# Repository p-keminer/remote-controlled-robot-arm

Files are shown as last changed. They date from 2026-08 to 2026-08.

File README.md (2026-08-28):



<div align="center">




</div>

---

# IMU Robotic Arm

Ein tragbarer Controller uebertraegt Armbewegungen auf einen modifizierten
Adeept-5-DOF-Roboterarm. Drei `BNO055`-IMUs erfassen Hand, Unterarm und Oberarm;
ein Potentiometer steuert den Greifer.

Der Prototyp besitzt zwei bewusst getrennte Datenpfade:

```text
Realer Steuerpfad
3x BNO055 + Potentiometer
  -> ESP32-S3 Controller
  -> ESP-NOW, Kanal 1
  -> ESP32-S3 Receiver
  -> I2C, Slave 0x42
  -> Arduino-kompatibles ATmega328P-Board
  -> 5 Servos

Debug- und Twin-Pfad
ESP32-S3 Controller
  -> zweiter ESP-NOW-Peer
  -> ESP32-S3 Bridge
  -> WiFi / MQTT / Raspberry Pi
  -> Dashboard, MCP und ROS 2
```

Der Debug-/Twin-Stack ist ein aktiver Bestandteil des Projekts. Er beobachtet
und visualisiert den Sensorstrom, liegt aber nicht im realen Servo-Steuerpfad.

## Demos

### ROS-2-Digital-Twin

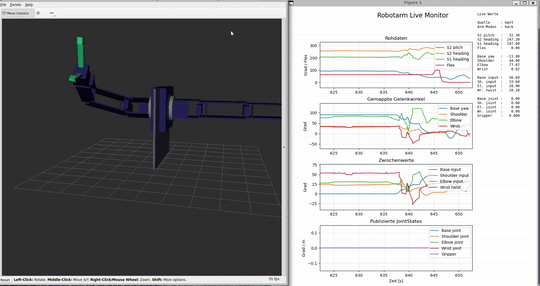
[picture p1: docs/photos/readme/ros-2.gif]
ROS-2-Digital-Twin


### Finaler Prototyp

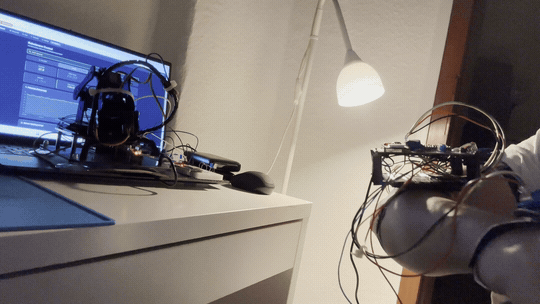
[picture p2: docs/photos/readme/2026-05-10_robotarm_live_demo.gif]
Finaler Prototyp Live-Demo


## Aktueller Stand

- Der vollstaendige Funk- und `I2C`-Pfad wurde am realen Prototyp getestet.
- Der eingecheckte Receiver startet weiterhin im `I2C`-Test-Sweep. Dieser Modus
  bewegt den Arm automatisch und ist keine Safety-Freigabe.
- `Live-I2C` und alle Live-Achsen bleiben im Repo-Default deaktiviert und werden
  nur bewusst per Compile-Flags aktiviert.
- Controller, Receiver-Default, Receiver-Live und Arduino-Sketch wurden mit den
  in [docs/BUILD.md](docs/BUILD.md#deutsch) festgehaltenen Versionen kompiliert.
- Bridge, `MQTT`, Dashboard, `MCP` und `ROS 2` bilden den aktiven Debug-/Twin-Pfad.
- Der Prototyp besitzt keine formale Produktiv-, Safety- oder Security-Freigabe.

Wichtig: Das Mapping des realen Arms und das Mapping der digitalen Zwillinge
sind derzeit nicht identisch. Die jeweiligen Implementierungen und Grenzen
sind in [docs/PROTOCOL.md](docs/PROTOCOL.md#deutsch) dokumentiert.

## Repository

- `firmware/`: aktive Controller-, Receiver-, Bridge- und Arduino-Firmware
- `firmware/archive/`: historische ESP-NOW-, UART- und Bring-up-Sketches
- `dashboard/`: Web-Dashboard und MQTT-MCP-Werkzeuge
- `ros2/`: ROS-2-Digital-Twin, Live-Monitor, Recorder und Replay
- `calibration/`: aktuelle Sensor-, Referenz- und Mappingdaten
- `docs/`: Hardware-, Protokoll-, Build- und Testdokumentation
- `tests/`: statische Guards fuer zeitkritische Firmwarepfade
- `scripts/`: lokale Pflege-, Sync- und Secret-Scan-Helfer
- `official_downloads/`: Herstellerlinks und Herkunftshinweise, kein Build-Input

## Einstieg

1. [docs/BUILD.md](docs/BUILD.md#deutsch) fuer Toolchain, Abhaengigkeiten und Builds
2. [docs/HARDWARE.md](docs/HARDWARE.md#deutsch) fuer Pins, Verdrahtung und Servolimits
3. [docs/PROTOCOL.md](docs/PROTOCOL.md#deutsch) fuer Steuer- und Debugdatenpfade
4. [calibration/README.md](calibration/README.md) fuer Referenzpose und Mapping
5. [SAFETY.md](SAFETY.md#deutsch) vor jeder Bewegung am realen Arm
6. [SECURITY.md](SECURITY.md#deutsch) vor Netz-, MQTT-, MCP- oder OTA-Betrieb
7. [docs/TESTING.md](docs/TESTING.md#deutsch) fuer bestaetigte und noch offene Nachweise
8. [dashboard/README.md](dashboard/README.md) und [ros2/README.md](ros2/README.md)
   fuer den Debug-/Twin-Stack

## Sicherheitsgrenze

Der Taster an `GPIO21` ist ein Software-Notaus-Request. Er trennt weder die
Servoversorgung noch das Drehmoment und ist kein fail-safe Hardware-Notaus.
Timeout- und Neutralverhalten fahren Zielwerte ueber die vorhandene
Slew-Begrenzung an. Details stehen in [SAFETY.md](SAFETY.md#deutsch).

## Lokale Konfiguration

Echte MAC-Adressen, WLAN-/MQTT-Zugangsdaten, Schluessel und lokale Pfade werden
nicht eingecheckt. Fuer Controller und Bridge existieren Templates; lokale
Dateien enden auf `*.local.*` und bleiben durch `.gitignore` ausgeschlossen.

Vor einem Push:

```bash
tr -d '\r' < scripts/secret_scan.sh | bash -s -- --tracked
```

## Lizenz

Projekt-eigene Inhalte stehen unter der [Apache License 2.0](LICENSE.md).
Verlinktes Hersteller- und Drittmaterial behaelt seine jeweiligen Lizenz- und
Urheberrechtsbedingungen.

<div align="center">



</div>

---

# IMU Robotic Arm

A wearable controller transfers arm movements to a modified Adeept 5-DOF
robotic arm. Three `BNO055` IMUs track the hand, forearm, and upper arm; a
potentiometer controls the gripper.

The prototype has two deliberately separated data paths:

```text
Real control path
3x BNO055 + potentiometer
  -> ESP32-S3 controller
  -> ESP-NOW, channel 1
  -> ESP32-S3 receiver
  -> I2C, slave 0x42
  -> Arduino-compatible ATmega328P board
  -> 5 servos

Debug and digital-twin path
ESP32-S3 controller
  -> second ESP-NOW peer
  -> ESP32-S3 bridge
  -> WiFi / MQTT / Raspberry Pi
  -> dashboard, MCP, and ROS 2
```

The debug/digital-twin stack is an active part of the project. It observes and
visualizes the sensor stream, but it is not part of the real servo-control path.

## Demos

### ROS 2 Digital Twin

ROS 2 digital twin

### Final Prototype

Final prototype live demo

## Current Status

- The complete radio and `I2C` path has been tested on the real prototype.
- The committed receiver still starts in the `I2C` test sweep. This mode moves
  the arm automatically and is not a safety approval.
- `Live I2C` and all live axes remain disabled in the repository defaults and
  are enabled deliberately through compile flags only.
- The controller, receiver default, receiver live configuration, and Arduino
  sketch were compiled with the versions recorded in [docs/BUILD.md](docs/BUILD.md#english).
- The bridge, `MQTT`, dashboard, `MCP`, and `ROS 2` form the active debug/digital-twin path.
- The prototype has no formal production, safety, or security approval.

Important: The real-arm mapping and the digital-twin mapping are currently not
identical. Their respective implementations and limitations are documented in
[docs/PROTOCOL.md](docs/PROTOCOL.md#english).

## Repository

- `firmware/`: active controller, receiver, bridge, and Arduino firmware
- `firmware/archive/`: historical ESP-NOW, UART, and bring-up sketches
- `dashboard/`: web dashboard and MQTT MCP tools
- `ros2/`: ROS 2 digital twin, live monitor, recorder, and replay
- `calibration/`: current sensor, reference, and mapping data
- `docs/`: hardware, protocol, build, and test documentation
- `tests/`: static guards for time-critical firmware paths
- `scripts/`: local maintenance, synchronization, and secret-scan helpers
- `official_downloads/`: manufacturer links and provenance notes, not a build input

## Getting Started

1. [docs/BUILD.md](docs/BUILD.md#english) for the toolchain, dependencies, and builds
2. [docs/HARDWARE.md](docs/HARDWARE.md#english) for pins, wiring, and servo limits
3. [docs/PROTOCOL.md](docs/PROTOCOL.md#english) for control and debug data paths
4. [calibration/README.md](calibration/README.md) for the reference pose and mapping
5. [SAFETY.md](SAFETY.md#english) before moving the real arm
6. [SECURITY.md](SECURITY.md#english) before operating networking, MQTT, MCP, or OTA
7. [docs/TESTING.md](docs/TESTING.md#english) for confirmed and outstanding evidence
8. [dashboard/README.md](dashboard/README.md) and [ros2/README.md](ros2/README.md)
   for the debug/digital-twin stack

## Safety Boundary

The button on `GPIO21` is a software emergency-stop request. It disconnects
neither servo power nor torque and is not a fail-safe hardware emergency stop.
Timeout and neutral behavior approach their targets through the existing slew
limit. See [SAFETY.md](SAFETY.md#english) for details.

## Local Configuration

Real MAC addresses, WiFi/MQTT credentials, keys, and local paths are not
committed. Templates are available for the controller and bridge; local files
end in `*.local.*` and remain excluded through `.gitignore`.

Before pushing:

```bash
tr -d '\r' < scripts/secret_scan.sh | bash -s -- --tracked
```

## License

Project-owned content is available under the [Apache License 2.0](LICENSE.md).
Linked manufacturer and third-party material retains its respective licensing
and copyright terms.

<div align="center">



</div>

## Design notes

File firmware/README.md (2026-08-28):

# Firmware

## Aktive Komponenten

| Pfad | Aufgabe |
|---|---|
| `esp32_controller/` | drei BNO055 ueber PCA9548A lesen, Potentiometer erfassen und `ImuPaket v4` senden |
| `esp32_receiver/` | ESP-NOW-Pakete validieren, auf Servo-Zielbytes abbilden und per I2C senden |
| `arduino_arm/` | I2C-Frames validieren, Servolimits und Slew-Rate anwenden |
| `esp32_bridge/` | zweiten ESP-NOW-Peer beobachten und Daten per MQTT an den Debug-/Twin-Stack geben |
| `archive/` | historische ESP-NOW-, UART- und Bring-up-Sketches; nicht aktiv bauen oder flashen |

## Steuerpfad

```text
esp32_controller/esp32_controller.ino
  -> ESP-NOW, ImuPaket v4, Kanal 1
esp32_receiver/esp32_receiver.ino
  -> I2C Frame V1, GPIO13/14, Slave 0x42
arduino_arm/arduino_arm.ino
  -> 5 Servos
```

Der Receiver-Default ist absichtlich konservativ:

```c
RECEIVER_MODE_TEST_SWEEP=1
RECEIVER_MODE_LIVE_I2C=0
RECEIVER_LIVE_ENABLE_BASIS=0
RECEIVER_LIVE_ENABLE_SHOULDER=0
RECEIVER_LIVE_ENABLE_ELBOW=0
RECEIVER_LIVE_ENABLE_WRIST=0
RECEIVER_LIVE_ENABLE_GRIPPER=0
```

Der Live-All-Axes-Build und der reale Prototyptest wurden bewusst ueber
Compile-Flags durchgefuehrt. Die exakten Befehle stehen in
[docs/BUILD.md](../docs/BUILD.md); Testgrenzen stehen in
[docs/TESTING.md](../docs/TESTING.md).

## Debug-/Twin-Pfad

Der Controller kann dasselbe Paket an einen zweiten ESP-NOW-Peer senden. Die
Bridge leitet diesen Beobachtungsstrom ueber WiFi/MQTT zum Raspberry Pi weiter.
Dashboard, MCP und ROS 2 sind aktive Debugwerkzeuge, aber keine Glieder des
Servo-Steuerpfads.

- Bridge-Firmware: `esp32_bridge/esp32_bridge.ino`
- Dashboard und MCP: [dashboard/README.md](../dashboard/README.md)
- ROS-2-Digital-Twin: [ros2/README.md](../ros2/README.md)

## Lokale Konfiguration

Vor einem lokalen Build die Templates kopieren und nur die gitignorierten
lokalen Dateien befuellen:

- Controller: `esp32_controller/peer_config.template.h` -> `peer_config.local.h`
- Bridge: `esp32_bridge/peer_config.template.h` -> `peer_config.local.h`
- Bridge: `esp32_bridge/wifi_config.template.h` -> `wifi_config.local.h`

Keine echten MACs, WLAN-/MQTT-Zugangsdaten oder Schluessel committen.

## Kanonische Dokumentation

- Build und Versionen: [docs/BUILD.md](../docs/BUILD.md)
- Verdrahtung und Servolimits: [docs/HARDWARE.md](../docs/HARDWARE.md)
- Pakete, Topics und Mappings: [docs/PROTOCOL.md](../docs/PROTOCOL.md)
- Referenzpose und Kalibrierung: [calibration/README.md](../calibration/README.md)
- Safety-Grenzen: [SAFETY.md](../SAFETY.md)
- Security-Grenzen: [SECURITY.md](../SECURITY.md)
- Teststatus: [docs/TESTING.md](../docs/TESTING.md)

Die Pfade `I2C_FRAME_V1.md` und `SERVO_UART_DESIGNENTSCHEIDUNGEN.md` bleiben
als kurze Kompatibilitaetsdokumente erhalten, weil aktive und archivierte
Quellkommentare darauf verweisen.

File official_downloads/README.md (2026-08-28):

# Herstellerreferenz

Dieser Ordner enthaelt nur Bezugsquellen und Herkunftshinweise zum verwendeten
Adeept-Grundkit. Herstellerarchive und entpackte Herstellerdateien werden nicht
versioniert; sie sind kein Build-Input und beschreiben nicht den heutigen
Prototyp mit ESP32-Steuerpfad, Potentiometer-Greifer und Debug-/Twin-Stack.

Offizielle Bezugsquellen:

- [Adeept Robotic Arm UNO](https://www.adeept.com/robotic-arm-uno_p0118.html)
- [Adeept Learn, Detail 64](https://www.adeept.com/learn/detail-64.html)

Regeln:

- Herstellerarchive und entpackte Vendor-Baeume werden nicht eingecheckt.
- Bei Bedarf werden Herstellerdateien erneut aus den offiziellen Quellen bezogen.
- Aktive Entscheidungen stehen in [`docs/HARDWARE.md`](../docs/HARDWARE.md),
  nicht in den Herstellerbeispielen.

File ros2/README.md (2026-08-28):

# ROS 2 Digital Twin

Dieses Verzeichnis enthaelt den ROS-2-/RViz-Digital-Twin fuer den Adeept
5-DOF-Arm. Er liest Telemetrie aus dem MQTT-Debugpfad, berechnet
Gelenkpositionen und visualisiert oder protokolliert sie. Er steuert keine
Servos und ist kein Safety-Pfad.

```text
Bridge --MQTT robotarm/imu--> mqtt_bridge
       --ROS /joint_states--> robot_state_publisher --> RViz
                            \-> Recorder / Live-Monitor / Replay
```

## Inhalt

| Pfad | Aufgabe |
| --- | --- |
| `src/robotarm_description/urdf/` | Tisch- und Wandmodell |
| `src/robotarm_description/meshes/` | eingecheckte STL-Geometrien |
| `src/robotarm_description/launch/` | RViz-, Live-, Debug- und Replay-Launches |
| `src/robotarm_description/robotarm_description/mapping.py` | Twin-Mapping |
| `.../mqtt_bridge.py` | MQTT-Eingang und ROS-Publisher |
| `.../debug_recorder.py` | JSONL-Aufzeichnung einer Debug-Session |
| `.../imu_replayer.py` | zeitgetreues Replay von `raw_imu.jsonl` |
| `.../live_monitor.py` | Matplotlib-Livekurven |
| `.../debug_plot.py` | PNG-Kurven aus einer Session |
| `start_*.sh`, `plot_*.sh`, `stop_*.sh` | Start- und Diagnosehelfer |

## Voraussetzungen und Build

Der verifizierte Zielkontext ist ROS 2 Jazzy unter WSL mit WSLg. Benoetigt
werden mindestens:

- ROS-Pakete fuer `rclpy`, `sensor_msgs`, `std_msgs`, `std_srvs`,
  `robot_state_publisher`, `joint_state_publisher_gui` und `rviz2`
- Python-Pakete `paho-mqtt` und `matplotlib`
- ein Tk-Backend fuer den Live-Monitor
- `numpy` und `trimesh` nur, wenn die eingecheckten STL-Dateien neu erzeugt
  werden sollen

Build ab dem Verzeichnis `ros2/`:

```bash
cd <pfad-zum-repo>/ros2
source /opt/ros/jazzy/setup.bash
rosdep install --from-paths src --ignore-src -r -y
colcon build --symlink-install --packages-select robotarm_description
source install/setup.bash
```

Vor einem Live-Start muessen sich `paho.mqtt.client` und fuer den Debug-Start
auch `matplotlib` im selben Python-Kontext wie ROS importieren lassen.

## MQTT konfigurieren

Die Startskripte laden optional eine lokale, gitignorierte Datei:

```bash
cp robotarm_mqtt.template.sh robotarm_mqtt.local.sh
chmod 600 robotarm_mqtt.local.sh
```

| Variable | Standard ohne lokale Datei | Bedeutung |
| --- | --- | --- |
| `ROBOTARM_MQTT_HOST` | `localhost` | Mosquitto-Host |
| `ROBOTARM_MQTT_PORT` | `1883` | MQTT-Port |
| `ROBOTARM_MQTT_USER` | `mcp_reader` | nur lesender Broker-Account |
| `ROBOTARM_MQTT_PASS` | leer | lokales Passwort |
| `ROBOTARM_TARGET_ARM` | `both` | `front`, `back` oder `both` |
| `ROBOTARM_RECORD_DEBUG` | `true` | Recorder im Debug-Launch |
| `ROBOTARM_SHOW_LIVE_MONITOR` | `true` | Live-Monitor im Debug-Launch |
| `ROBOTARM_DEBUG_DIR` | `ros2/debug_sessions` | lokale Session-Ausgabe |

Passwoerter und lokale Hosts werden nur in `robotarm_mqtt.local.sh` gepflegt.
Die Datei darf nicht eingecheckt werden.

## Starten

Alle folgenden Befehle gelten **nach** `cd <pfad-zum-repo>/ros2`; deshalb
enthalten die Pfade kein zusaetzliches `./ros2/`.

Nur RViz mit Gelenkslidern, ohne MQTT:

```bash
./start_rviz.sh          # Tischmodell
./start_rviz_wall.sh     # zwei gespiegelte Wandarme
```

Live-Twin aus `robotarm/imu`:

```bash
./start_live_wall.sh
```

Live-Twin mit Recorder und optionalem Matplotlib-Monitor:

```bash
./start_live_wall_debug.sh
```

Die beiden Live-Skripte rufen vorher `stop_live_wall_stack.sh` auf. Dieses
Skript beendet passende ROS-/RViz-/Monitor-Prozesse mit `kill -9` und sollte
daher nur in der dafuer vorgesehenen WSL-Sitzung verwendet werden.

Der Wand-Launch kennt drei Zielmodi:

- `front`: nur linker Arm
- `back`: nur rechter Arm
- `both`: beide gespiegelten Arme

Zur Laufzeit wechselt der Dienst zyklisch `front -> back -> both`:

```bash
ros2 service call /toggle_arm std_srvs/srv/Trigger '{}'
```

## Debug-Session, Replay und Plot

Der Debug-Launch schreibt standardmaessig nach
`debug_sessions/<YYYYMMDD_HHMMSS>/`:

- `raw_imu.jsonl`
- `mapping.jsonl`
- `joint_states.jsonl`
- `session.json`
- optional `curves.png`

`debug_sessions/` ist gitignoriert. Vor einem Replay sollte ein laufender
Live-Stack explizit beendet werden:

```bash
./stop_live_wall_stack.sh
./start_replay_wall.sh debug_sessions/<timestamp>/raw_imu.jsonl
./start_replay_wall.sh debug_sessions/<timestamp>/raw_imu.jsonl 0.5
```

Plot der neuesten oder einer bestimmten Session:

```bash
./plot_debug_session.sh
./plot_debug_session.sh debug_sessions/<timestamp>
```

## Schnittstellen

### MQTT-Eingang

Der ROS-Node `mqtt_bridge` abonniert nur `robotarm/imu`. Die MQTT-Topics
`robotarm/status`, `robotarm/kalib` und `robotarm/ota/log` werden von diesem
Paket nicht konsumiert.

### ROS-2-Ausgabe

| ROS-Name | Typ | Erzeuger | Aktiv wenn |
| --- | --- | --- | --- |
| `/joint_states` | `sensor_msgs/JointState` | MQTT-Bridge oder Replay | Live/Replay |
| `/robotarm/debug/raw_imu` | `std_msgs/String` | MQTT-Bridge oder Replay | `publish_debug=true` |
| `/robotarm/debug/mapping` | `std_msgs/String` | MQTT-Bridge oder Replay | `publish_debug=true` |
| `robot_description` | Node-Parameter | Launch-Datei | jeder Launch |
| `/tf`, `/tf_static` | TF | `robot_state_publisher` | jeder Launch |
| `/toggle_arm` | `std_srvs/Trigger` | MQTT-Bridge | Live |

Die Namen mit fuehrendem `/` sind ROS-2-Namen und duerfen nicht als
MQTT-Topics dokumentiert oder in Mosquitto abonniert werden.

## Twin-Mapping

`mapping.py` und `dashboard/web/js/robotarm_3d.js` verwenden denselben
Twin-Stand:

| Gelenk | Twin-Eingang |
| --- | --- |
| Basis | `88.9 - S2.pitch`, visuell `+90..-90` Grad |
| Schulter | negierte Heading-Abweichung von `S2` zu `280.8` Grad |
| Ellbogen | relative Heading-Abweichung `S1` zu `S2` |
| Wrist | negierte relative Roll-Abweichung `S0` zu `S1`, Offset und Stabilisierung |
| Greifer | `f` in Prozent, invertiert auf die visuelle Oeffnung und geglaettet |

Dieses Twin-Mapping ist nicht identisch mit dem Realarm-Mapping in
[`live_i2c_mapping.h`](../firmware/esp32_receiver/live_i2c_mapping.h). Dort
weichen unter anderem Basisrichtung, Schulterreferenz/-fenster und die
Wrist-Fallback-/Nullungslogik ab. Konstanten duerfen deshalb nicht ungeprueft
zwischen Twin und Receiver kopiert werden.

## Test und Diagnose

Pakettests nach einem Build:

```bash
colcon test --packages-select robotarm_description
colcon test-result --verbose
```

Schneller Laufzeitcheck bei gestartetem Live-Stack:

```bash
ros2 topic echo --once /joint_states
ros2 topic hz /joint_states
ros2 topic echo --once /robotarm/debug/mapping
```

Der letzte Befehl liefert nur im Debug-Launch Daten. Bei DDS-Problemen kann
`test_dds.template.sh` nach `test_dds.local.sh` kopiert und der lokale Pfad
angepasst werden.

## Bekannte Grenzen

- Das Paket ist ein Debug-/Simulationspfad und besitzt keinen Servo-Ausgang.
- `fastdds_profile.xml` erzwingt Shared Memory und ist fuer Prozesse auf
  demselben WSL-Host gedacht, nicht fuer verteilte ROS-Rechner.
- Der Live-Pfad stabilisiert Wrist und Greifer zustandsbehaftet. Das Replay
  nutzt zwar dasselbe Grundmapping, wendet diese Live-Stabilisierung aber
  derzeit nicht an und ist daher nicht samplegenau identisch.
- `mapping.py` publiziert den Wrist-Zwischenwert als `roll_rel_deg`; Plot und
  Live-Monitor suchen aktuell noch `twist_rel_deg`. Die betreffende
  Zwischenwert-Kurve bleibt dadurch leer, waehrend Gelenkwinkel und
  `/joint_states` weiter funktionieren.
- Die Standard-Lintertests decken Stil ab, aber keine numerischen
  Mapping-Grenzfaelle.

Weitere Details stehen in
[`dashboard/README.md`](../dashboard/README.md),
[`docs/PROTOCOL.md`](../docs/PROTOCOL.md),
[`docs/TESTING.md`](../docs/TESTING.md) und
[`SECURITY.md`](../SECURITY.md).

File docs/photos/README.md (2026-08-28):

# docs/photos

## Zweck

Dieser Ordner enthaelt Bildnachweise fuer Aufbau, Montage, Sensorlage und Verkabelung.

## Aktueller Stand

Fotos des Stock-Aufbaus, des fruehen Bench-Setups und des finalen Prototypstands sind als JPG dokumentiert.
README- und Demo-GIFs werden getrennt unter `readme/` gepflegt.

## Inhalt

- `2026-03-24_roboterarm_seitenansicht.jpg` - Adeept-Arm Seitenansicht (Stock-Zustand)
- `2026-03-24_roboterarm_rueckansicht.jpg` - Adeept-Arm Rueckansicht (Stock-Zustand)
- `2026-03-24_roboterarm_basis_detail.jpg` - Adeept-Arm Basis-Detail (Stock-Zustand)
- `2026-03-26_bench_breadboards_uebersicht.jpg` - Bench-Setup mit Controller und Receiver Breadboards
- `2026-03-26_bench_breadboards_detail.jpg` - Bench-Breadboard Detail (IMU-Verkabelung)
- `2026-03-28_bench_aufbau_aktuell.jpg` - aktueller Bench-Aufbau
- `2026-05-10_robotarm_finaler_prototyp.jpg` - finaler Robotarm-Prototypstand
- `readme/` - GIFs und Medien fuer README-/Demo-Nachweise

## Regeln

- Fotos als JPG ablegen, damit sie ohne HEIC-Sonderunterstuetzung nutzbar bleiben
- Bilder so benennen, dass Datum, Zweck oder Aufbauzustand erkennbar sind
- wenn ein Foto eine Kalibrier- oder Sicherheitsentscheidung stuetzt, sollte es querreferenziert werden

## Schnittstellen/Abhaengigkeiten

- ergaenzt `hardware/`, `calibration/reference_poses/` und `docs/measurement_logs/`

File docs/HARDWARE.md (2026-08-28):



<div align="center">




</div>

---

# Hardware

Diese Datei ist die kompakte Hardware-Referenz des aktuellen Prototyps. Sie
beschreibt den real aufgebauten Projektpfad; Herstellerstand und fruehe
Breadboard-/UART-/Flex-Sensor-Staende sind keine aktive Verdrahtung.

Der Arm ist ein funktionsfaehiger Entwicklungsprototyp, aber kein
sicherheitszertifiziertes Produkt. Vor realer Bewegung gelten zusaetzlich die
Einschraenkungen aus [`SAFETY.md`](../SAFETY.md#deutsch).

## Aktive Komponenten

- Adeept 5-DOF Roboterarm mit ATmega328P-basiertem Driver Board
  (`arduino:avr:uno`)
- fuenf aktive AD002-Servos; der urspruengliche Schulterservo wurde durch den
  damaligen Reserveservo ersetzt, ein weiterer Reserveservo ist nicht vorhanden
- drei ESP32-S3-WROOM-1-N16R8: Controller, Receiver und separate Debug-Bridge;
  ein viertes Board ist Reserve
- Boardrevision v1.0 mit 16 MB Flash, 8 MB Octal-PSRAM und RGB-LED auf `GPIO48`
- drei GY-BNO055-Module an einem PCA9548A-Multiplexer
- 10-kOhm-Potentiometer als aktive Greifer-Eingabe
- zwei Molicel INR-18650-M35A im Adeept-Batteriehalter; zwei weitere Zellen als
  Wechselakkus, Ladegeraet XTAR VC4SL

Fuer die ESP32 gilt die Custom-FQBN
`esp32:esp32:robotic_arm_s3n16r8`. `GPIO35`, `GPIO36` und `GPIO37` sind durch das
Octal-PSRAM belegt und nicht fuer Projekt-I/O verfuegbar.

## Controller und Sensorik

| Signal | Anschluss | Gegenstelle / Funktion |
| --- | --- | --- |
| ADC Greifer | `GPIO1` | Poti-Wischer; 10-kOhm-Pull-down bleibt am Controller |
| I2C SDA | `GPIO8` | PCA9548A SDA |
| I2C SCL | `GPIO9` | PCA9548A SCL |
| IMU-Status S2 | `GPIO4` | blaue LED, Oberarm |
| IMU-Status S1 | `GPIO5` | rote LED, Unterarm |
| IMU-Status S0 | `GPIO6` | weisse LED, Hand/Wrist |
| Kommunikation | `GPIO7` | gruene LED |
| Fehler | `GPIO10` | externe FAULT-LED |
| Software-Stop | `GPIO21` | Taster nach GND, interner Pull-up |
| RGB | `GPIO48` | onboard, Fehler-/Stop-Anzeige |

PCA9548A-Adresse: `0x70`. Alle drei BNO055 verwenden hinter getrennten
Mux-Kanaelen die Adresse `0x29`.

| Mux-Kanal | Datenindex | Koerpersegment |
| --- | --- | --- |
| `0` | `S0` | Hand/Wrist |
| `1` | `S1` | Unterarm |
| `2` | `S2` | Oberarm |

Das Potentiometer ist im bestaetigten 2-Draht-Aufbau angeschlossen: `3.3 V` an
einem aeusseren Pin, Wischer an `GPIO1`; der vorhandene 10-kOhm-Pull-down zieht
den ADC-Knoten nach GND. Die aktiven Kalibrieranker stehen in
[`calibration/README.md`](../calibration/README.md).

## Receiver, Arduino und I2C

| Signal | ESP32-Receiver | Adeept-/Arduino-Board |
| --- | --- | --- |
| SDA | `GPIO13` | `A4`, OLED-Header Pin 3 |
| SCL | `GPIO14` | `A5`, OLED-Header Pin 4 |
| Masse | `GND` | `GND`, gemeinsamer Bezug |

- ESP32: I2C-Master mit `100 kHz`
- Arduino: I2C-Slave `0x42`
- Transport: festes 11-Byte-Frame V1
- das OLED muss waehrend dieser Verbindung ausgesteckt bleiben, weil es denselben
  Busanschluss belegt
- Receiver-Status: `GPIO4` I2C, `GPIO5` ESP-NOW/LINK, `GPIO48` RGB

Die aktive Definition liegt in
[`i2c_frame.h`](../firmware/esp32_receiver/i2c_frame.h) und
[`arduino_arm.ino`](../firmware/arduino_arm/arduino_arm.ino).

### I2C-Pegel: vor Betrieb verifizieren

Der ESP32-S3 arbeitet mit `3.3 V`, das ATmega328P-Board mit `5 V`. I2C ist
Open-Drain; der HIGH-Pegel wird daher durch die tatsaechlich vorhandenen
Pull-ups bestimmt. Eine funktionierende Bench-Verbindung beweist nicht, dass
am ESP32 ein zulaessiger Pegel anliegt. Die fruehere Annahme, interne
ATmega-Pull-ups seien ohne Pegelanpassung unkritisch, ist keine belastbare
Freigabe.

Vor erneutem Anschluss an einen ESP32:

1. alle Pull-ups auf Driver Board, OLED-Header und Zusatzmodulen identifizieren;
2. SDA und SCL im Leerlauf gegen GND messen;
3. sicherstellen, dass beide Leitungen auf der ESP32-Seite auf `3.3 V`
   hochgezogen werden und dort niemals oberhalb des Datenblattbereichs liegen;
4. bei `5 V` oder unbekannter Beschaltung einen bidirektionalen, fuer
   Standard-Mode-I2C geeigneten Levelshifter einsetzen oder die Pull-ups
   nachweislich auf `3.3 V` legen;
5. erst danach ESP32, Arduino und gemeinsame Masse verbinden.

`5 V` direkt an einem ESP32-S3-GPIO ist nicht freigegeben. Bis Pull-up-Spannung
und Leerlaufpegel dokumentiert sind, bleibt diese elektrische Schnittstelle ein
offener Safety-Punkt.

## Servoanschluesse und aktive Grenzen

Die reale Belegung weicht vom Adeept-Stock-Mapping ab. Die aktive Firmware
mappt jeweils den Bytebereich `0..255` auf die gemessenen Min-/Max-Werte.

| Gelenk | PWM-Pin | Stock-Poti | Min | Max | aktiver Start-/Rueckfallwert |
| --- | ---: | ---: | ---: | ---: | ---: |
| Basis | `D9` | `A0` | 12 Grad | 139 Grad | 75 Grad |
| Schulter | `D11` | `A6` | 35 Grad | 142 Grad | 88 Grad |
| Ellbogen | `D3` | `A3` | 80 Grad | 175 Grad | 127 Grad |
| Handgelenk | `D5` | `A2` | 5 Grad | 177 Grad | 91 Grad |
| Greifer | `D6` | `A1` | 32 Grad | 126 Grad | 79 Grad |

Die Werte `75/88/127/91/79` sind die ganzzahligen Mittelpunkte der aktiven
Grenzen. `90 Grad` war ein historischer Montage-/Kalibrierstand, ist aber nicht
die aktuelle Start-, Timeout- oder Software-Stop-Pose. Die Grenzen wurden
empirisch am Prototyp bestimmt; sie sind kein normativer Sicherheitsnachweis.

## Debug-Bridge

Die Bridge ist ein eigener Beobachtungsknoten und gehoert nicht zum
Bewegungsweg.

| Signal | Pin |
| --- | --- |
| WiFi-Status | `GPIO4` |
| ESP-NOW-Status | `GPIO5` |
| MQTT-Status | `GPIO7` |
| RGB | `GPIO48` |

Ihr Ausfall darf den Pfad `Controller -> Receiver -> Arduino -> Servos` nicht
veraendern.

## Stromversorgung

- Mehrservo-Bewegung wird nicht aus dem USB-Uploadpfad freigegeben.
- Der bestaetigte Prototyppfad nutzt zwei qualifizierte 18650-Zellen im
  Adeept-Batteriehalter; USB dient Upload und Diagnose.
- Servolast und empfindliche Logikversorgung sind getrennt zu planen, brauchen
  fuer die Signale aber einen bewusst hergestellten gemeinsamen Massebezug.
- Verschiedene Versorgungen duerfen nicht unbeabsichtigt ueber USB, Header oder
  Breadboard parallelgeschaltet werden.
- Stromaufnahme, Sicherung, Leitungsquerschnitt, Steckverbindungen und
  Zugentlastung sind vor einem Dauerbetrieb noch nachzuweisen.

## Primaerquellen

- [Aktive Controller-Firmware](../firmware/esp32_controller/esp32_controller.ino)
- [Aktive Receiver-Firmware](../firmware/esp32_receiver/esp32_receiver.ino)
- [Aktive Arduino-Firmware](../firmware/arduino_arm/arduino_arm.ino)
- [ESP32-S3 Series Datasheet](https://documentation.espressif.com/esp32_s3_datasheet_en.pdf)
  fuer Versorgungs- und GPIO-Pegelgrenzen
- [Arduino UNO Rev3](https://store.arduino.cc/products/arduino-uno-rev3) fuer
  ATmega328P und `5 V` Betriebsspannung
- [Microchip TWI-Beispiel](https://onlinedocs.microchip.com/oxy/GUID-317042D4-BCCE-4065-BB05-AC4312DBC2C4-en-US-2/GUID-DEDA6A06-3138-45C3-BB95-74E4CF6BC406.html)
  fuer Open-Drain-Bus und erforderliche Pull-ups

<div align="center">



</div>

---

# Hardware

This file is the compact hardware reference for the current prototype. It
describes the physically implemented project path; the vendor baseline and
early breadboard, UART, and flex-sensor stages are not active wiring.

The arm is a functional development prototype, but it is not a
safety-certified product. Before any physical movement, the restrictions in
[`SAFETY.md`](../SAFETY.md#english) also apply.

## Active components

- Adeept 5-DOF robotic arm with an ATmega328P-based driver board
  (`arduino:avr:uno`)
- five active AD002 servos; the original shoulder servo was replaced with the
  former spare servo, and no additional spare servo remains
- three ESP32-S3-WROOM-1-N16R8 boards: controller, receiver, and a separate
  debug bridge; a fourth board is reserved as a spare
- board revision v1.0 with 16 MB flash, 8 MB octal PSRAM, and an RGB LED on
  `GPIO48`
- three GY-BNO055 modules connected through one PCA9548A multiplexer
- one 10-kOhm potentiometer as the active gripper input
- two Molicel INR-18650-M35A cells in the Adeept battery holder; two additional
  cells as replacements, plus an XTAR VC4SL charger

The custom FQBN for the ESP32 boards is
`esp32:esp32:robotic_arm_s3n16r8`. `GPIO35`, `GPIO36`, and `GPIO37` are occupied
by the octal PSRAM and are not available for project I/O.

## Controller and sensors

| Signal | Connection | Counterpart / function |
| --- | --- | --- |
| Gripper ADC | `GPIO1` | potentiometer wiper; the 10-kOhm pull-down remains on the controller |
| I2C SDA | `GPIO8` | PCA9548A SDA |
| I2C SCL | `GPIO9` | PCA9548A SCL |
| IMU status S2 | `GPIO4` | blue LED, upper arm |
| IMU status S1 | `GPIO5` | red LED, forearm |
| IMU status S0 | `GPIO6` | white LED, hand/wrist |
| Communication | `GPIO7` | green LED |
| Fault | `GPIO10` | external FAULT LED |
| Software stop | `GPIO21` | button to GND, internal pull-up |
| RGB | `GPIO48` | onboard fault/stop indicator |

PCA9548A address: `0x70`. All three BNO055 modules use address `0x29` behind
separate multiplexer channels.

| Mux channel | Data index | Body segment |
| --- | --- | --- |
| `0` | `S0` | hand/wrist |
| `1` | `S1` | forearm |
| `2` | `S2` | upper arm |

The potentiometer uses the confirmed two-wire connection: `3.3 V` on one outer
pin and the wiper on `GPIO1`; the existing 10-kOhm pull-down draws the ADC node
to GND. The active calibration anchors are documented in
[`calibration/README.md`](../calibration/README.md).

## Receiver, Arduino, and I2C

| Signal | ESP32 receiver | Adeept/Arduino board |
| --- | --- | --- |
| SDA | `GPIO13` | `A4`, OLED header pin 3 |
| SCL | `GPIO14` | `A5`, OLED header pin 4 |
| Ground | `GND` | `GND`, common reference |

- ESP32: I2C master at `100 kHz`
- Arduino: I2C slave at `0x42`
- transport: fixed 11-byte Frame V1
- the OLED must remain disconnected while this link is used because it occupies
  the same bus connector
- receiver status: `GPIO4` for I2C, `GPIO5` for ESP-NOW/LINK, and `GPIO48` for RGB

The active definitions are in
[`i2c_frame.h`](../firmware/esp32_receiver/i2c_frame.h) and
[`arduino_arm.ino`](../firmware/arduino_arm/arduino_arm.ino).

### I2C levels: verify before operation

The ESP32-S3 operates at `3.3 V`, while the ATmega328P board operates at `5 V`.
I2C uses open-drain signaling, so the actual pull-ups determine the HIGH level.
A working bench connection does not prove that the voltage at the ESP32 is
within its permitted range. The earlier assumption that the internal ATmega
pull-ups are harmless without level adaptation is not a reliable approval.

Before reconnecting the interface to an ESP32:

1. identify every pull-up on the driver board, OLED header, and additional modules;
2. measure idle SDA and SCL against GND;
3. ensure that both lines are pulled up to `3.3 V` on the ESP32 side and never
   exceed the datasheet range there;
4. if the wiring uses `5 V` or is unknown, install a bidirectional level shifter
   suitable for Standard-mode I2C, or verifiably move the pull-ups to `3.3 V`;
5. only then connect the ESP32, Arduino, and common ground.

Applying `5 V` directly to an ESP32-S3 GPIO is not approved. Until the pull-up
voltage and idle levels are documented, this electrical interface remains an
open safety item.

## Servo connections and active limits

The physical assignment differs from the Adeept stock mapping. The active
firmware maps the byte range `0..255` to the measured minimum and maximum values
for each joint.

| Joint | PWM pin | Stock potentiometer | Min | Max | active start/fallback value |
| --- | ---: | ---: | ---: | ---: | ---: |
| Base | `D9` | `A0` | 12 degrees | 139 degrees | 75 degrees |
| Shoulder | `D11` | `A6` | 35 degrees | 142 degrees | 88 degrees |
| Elbow | `D3` | `A3` | 80 degrees | 175 degrees | 127 degrees |
| Wrist | `D5` | `A2` | 5 degrees | 177 degrees | 91 degrees |
| Gripper | `D6` | `A1` | 32 degrees | 126 degrees | 79 degrees |

The values `75/88/127/91/79` are the integer midpoints of the active limits.
`90 degrees` was a historical mounting and calibration state, but it is not the
current start, timeout, or software-stop pose. The limits were determined
empirically on the prototype; they are not a normative safety verification.

## Debug bridge

The bridge is a separate observation node and is not part of the motion path.

| Signal | Pin |
| --- | --- |
| WiFi status | `GPIO4` |
| ESP-NOW status | `GPIO5` |
| MQTT status | `GPIO7` |
| RGB | `GPIO48` |

Its failure must not change the
`Controller -> Receiver -> Arduino -> Servos` path.

## Power supply

- Multi-servo motion is not approved through the USB upload power path.
- The confirmed prototype path uses two qualified 18650 cells in the Adeept
  battery holder; USB is used for uploads and diagnostics.
- Servo load power and sensitive logic power should be planned separately, but
  their signals require a deliberately established common ground reference.
- Separate supplies must not be connected in parallel unintentionally through
  USB, headers, or a breadboard.
- Current draw, fuse protection, conductor sizing, connectors, and strain relief
  still require verification before continuous operation.

## Primary sources

- [Active controller firmware](../firmware/esp32_controller/esp32_controller.ino)
- [Active receiver firmware](../firmware/esp32_receiver/esp32_receiver.ino)
- [Active Arduino firmware](../firmware/arduino_arm/arduino_arm.ino)
- [ESP32-S3 Series Datasheet](https://documentation.espressif.com/esp32_s3_datasheet_en.pdf)
  for supply and GPIO voltage limits
- [Arduino UNO Rev3](https://store.arduino.cc/products/arduino-uno-rev3) for the
  ATmega328P and its `5 V` operating voltage
- [Microchip TWI example](https://onlinedocs.microchip.com/oxy/GUID-317042D4-BCCE-4065-BB05-AC4312DBC2C4-en-US-2/GUID-DEDA6A06-3138-45C3-BB95-74E4CF6BC406.html)
  for the open-drain bus and required pull-ups

<div align="center">



</div>

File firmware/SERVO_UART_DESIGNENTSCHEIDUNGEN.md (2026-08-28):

# Servo- und Transportentscheidungen

Dieser Pfad bleibt erhalten, weil aktive und archivierte Quellkommentare auf
die nummerierten Abschnitte verweisen. Kanonische Gesamtinformationen stehen in
[docs/HARDWARE.md](../docs/HARDWARE.md),
[docs/PROTOCOL.md](../docs/PROTOCOL.md) und [SAFETY.md](../SAFETY.md).

## 1. Historischer UART-Pfad

Der erste Receiver-Arduino-Pfad nutzte ESP32 GPIO15 als UART-TX und Arduino D2
als SoftwareSerial-RX bei 9600 Baud. Er ist vollstaendig unter
`firmware/archive/uart/` archiviert und kein aktiver Buildpfad.

## 2. Historisches Listen-/Servo-Zeitfenster

SoftwareSerial-PCINT und Timer1-Servo-PWM verursachten auf dem ATmega328P
sichtbaren Jitter. Der archivierte Sketch trennte deshalb ein 100-ms-Listenfenster
von Servo-PWM-Phasen. Diese Komplexitaet war ein Grund fuer die I2C-Migration.

## 3. Servo-Attach und Pinbelegung

Der aktive I2C-Sketch laesst alle Servos dauerhaft attached. Die bestaetigten
Pins sind:

| Achse | Pin |
|---|---:|
| Basis | D9 |
| Schulter | D11 |
| Ellbogen | D3 |
| Handgelenk | D5 |
| Greifer | D6 |

## 4. Mechanische Servolimits

| Achse | Minimum | Maximum |
|---|---:|---:|
| Basis | 12 | 139 |
| Schulter | 35 | 142 |
| Ellbogen | 80 | 175 |
| Handgelenk | 5 | 177 |
| Greifer | 32 | 126 |

Diese Werte sind empirische Betriebsgrenzen des aufgebauten Arms, keine
zertifizierten Schutzgrenzen. Sie duerfen nur nach einer erneuten physischen
Messung geaendert werden. Die Schultergrenze ist bewusst enger als der
theoretisch moegliche Weg.

## 5. Neutral- und Startwerte

Bytewert 128 wird pro Achse auf den Mittelpunkt des jeweiligen Limitbereichs
abgebildet. Die tatsaechlichen ganzzahligen Zielwerte sind daher:

```text
Basis 75, Schulter 88, Ellbogen 127, Handgelenk 91, Greifer 79
```

Pauschale 90 Grad sind nicht der aktive Neutralstand. Neutral, Timeout und
Software-ESTOP verwenden dieselben Mittelpunkte und fahren sie ueber die
Slew-Begrenzung an; sie trennen keine Leistung.

## 6. Sweep und Integergrenzen

Der Sweep arbeitet im Bytebereich um `SWEEP_NEUTRAL=128`. Sein Offset muss
`int16_t` sein. Ein `int8_t`-Offset kann an den Grenzen ueberlaufen und einen
Positionssprung erzeugen. Der aktive I2C-Sweep clampt deshalb bei +/-127.

## 9. Slew-Rate-Limiter

Der aktive Arduino-Sketch aktualisiert mit 50 Hz und begrenzt jede Achse auf
`MAX_SCHRITT=3` Grad pro Loop. Das entspricht rechnerisch maximal etwa
150 Grad/s. Der Receiver besitzt zusaetzliche Byte-Slew-Limits; die Arduino-
Grenze bleibt die letzte Servoebene.

## 11. Archivierter UART-Zyklus

Der UART-Sketch wechselte zwischen SoftwareSerial und Servo-PWM. Er bleibt nur
als Entwicklungsnachweis erhalten und darf nicht mit der aktiven I2C-Firmware
verwechselt werden.

## 12. Aktiver I2C-Test-Sweep

`firmware/esp32_receiver/test_sweep_i2c.h` erzeugt den eingecheckten
Receiver-Default. Er sendet alle 20 ms ein 11-Byte-Frame an Slave `0x42` und
testet die Servo-Kette ohne Live-Mapping. Die Datei bleibt erforderlich, solange
`RECEIVER_MODE_TEST_SWEEP=1` der Default ist.

## 13. I2C-Migration und ISR-Regel

Der aktive Pfad nutzt ESP32 GPIO13/14 zu Arduino A4/A5. Der Arduino-Empfangs-
Callback kopiert im Interruptkontext ausschliesslich die 11 Rohbytes in einen
Puffer. Startbytes, Version, XOR-Pruefsumme, Flags und `map()` werden erst im
normalen `loop()` verarbeitet. Rechenarbeit im ISR stoerte zuvor Timer1 und
fuehrte zu Servo-Zucken.

Das I2C-Spannungsniveau muss vor Betrieb gemaess [SAFETY.md](../SAFETY.md)
verifiziert werden.

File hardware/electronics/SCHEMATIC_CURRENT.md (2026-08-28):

# Aktueller Schaltungsstand

Diese Datei bleibt als Kompatibilitaetsziel fuer historische Quellcode-Verweise
erhalten. Die kanonische und aktuelle Verdrahtung steht in
[`docs/HARDWARE.md`](../../docs/HARDWARE.md); Betriebsgrenzen stehen in
[`SAFETY.md`](../../SAFETY.md).

Aktiver Bewegungsweg:

```text
Controller --ESP-NOW--> Receiver --I2C--> Arduino --> Servos
```

Separater Diagnoseweg:

```text
Controller --ESP-NOW--> Bridge --WiFi/MQTT--> Dashboard / MCP / ROS 2
```

Der archivierte UART-Pfad verwendete ESP32 `GPIO15` als TX und Arduino `D2`
als SoftwareSerial-RX. Er liegt nur noch unter
[`firmware/archive/uart/`](../../firmware/archive/uart/) und ist kein aktiver
Build- oder Flashpfad.

Die Bridge gehoert nicht zum Bewegungsweg. Der MCP-Server besitzt jedoch ein
Publish-Werkzeug und ist daher nur bei wirksamer Broker-ACL als read-only zu
behandeln; siehe [`SECURITY.md`](../../SECURITY.md).

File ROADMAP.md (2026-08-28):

# Roadmap

Diese Datei enthaelt nur noch offene oder dauerhaft relevante Arbeit. Erledigte
Einzelschritte bleiben ueber die Git-Historie und [docs/TESTING.md](docs/TESTING.md)
nachvollziehbar.

## Safety und reale Armfreigabe

- [ ] Hardware-Notaus beziehungsweise sichere Leistungsabschaltung definieren
- [ ] I2C-Pull-up- und Idle-Pegel zwischen ESP32-S3 und ATmega328P messen
- [ ] Timeout-, Neutral- und Recovery-Verhalten am realen Arm formal testen
- [ ] Dauerlauf-, Kollisions- und Ausfalltests dokumentieren
- [ ] entscheiden, ob Live-I2C jemals Repo-Default werden darf

## Security

- [ ] ESP-NOW-Verschluesselung und Schluessel-Provisioning festlegen
- [ ] Receiver auf erlaubte Sender-MAC beziehungsweise authentisierte Pakete begrenzen
- [ ] MQTT-, MCP- und OTA-Rechte auf notwendige Debugfunktionen reduzieren
- [ ] produktive Secrets und Geraeteidentitaeten reproduzierbar provisionieren

## Reproduzierbare Builds

- [ ] getestete ESP32-Core-Version nach Hardwaretest verbindlich pinnen
- [ ] fehlende Custom-Board-Definition `robotic_arm_s3n16r8` reproduzierbar ablegen
- [ ] Bash-Zeilenenden per `.gitattributes` fuer Windows-Checkouts festlegen
- [ ] Controller, Receiver, Bridge und Arduino in CI kompilieren
- [ ] PlatformIO-Konfigurationen gegen den Arduino-Hauptpfad angleichen

## Mapping und Digital Twin

- [ ] Mapping-Drift zwischen Realarm, Dashboard und ROS fachlich entscheiden
- [ ] gemeinsame Golden-Testvektoren fuer Realarm und Twins erstellen
- [ ] dokumentierte Neutral-/Referenzpose am realen Aufbau erneut bestaetigen
- [ ] ROS-/Dashboard-Diagnosefehler und Abhaengigkeiten separat pruefen

## Hardware und Betrieb

- [ ] aktuelle Stromversorgungs- und Sicherungswerte am finalen Aufbau messen
- [ ] Stock-/Learning-Mode des Adeept-Kits gegen den Projektstand abgrenzen
- [ ] Wearable und Perfboard fuer wiederholbare Montage kennzeichnen

## Spaeter

- [ ] mobile Plattform und Kamerasicht nur als getrennte Erweiterungen planen
- [ ] Aktuatorabstraktion fuer andere Armhardware entwerfen

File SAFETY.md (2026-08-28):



<div align="center">




</div>

---

# Safety

Der Roboterarm kann Personen verletzen und Bauteile beschaedigen. Der aktuelle Stand ist ein getesteter `Entwicklungsprototyp`, aber weder sicherheitszertifiziert noch fuer unbeaufsichtigten, industriellen, medizinischen oder anderweitig sicherheitskritischen Betrieb freigegeben.

Diese Datei beschreibt das tatsaechliche Verhalten der aktiven Firmware. Eine Quellcodefreigabe ist keine Betriebsfreigabe.

## Wichtigste Grenze: kein echter Not-Aus

Der Taster an `GPIO21` ist nur ein **Software-Stop-Toggle**. Er ist kein `fail-safe` Not-Aus und keine Leistungsabschaltung:

- der Controller startet `notaus_aktiv` bei jedem Boot explizit mit `false`;
- ein offener oder nicht angeschlossener Eingang liegt durch `INPUT_PULLUP` auf HIGH und startet damit **freigegeben**, nicht gestoppt;
- auch ein beim Boot gedrueckt gehaltener Taster verriegelt den Stop nicht verlaesslich, weil erst eine spaetere fallende Flanke den Zustand toggelt;
- der Zustand wird per ESP-NOW als Flag uebertragen und kann durch einen zweiten Tastendruck wieder aufgehoben werden;
- es gibt keine redundante Leitung, keine zwangsgefuehrten Kontakte, keine Rueckfuehrung und keinen Totmannpfad;
- Servos bleiben elektrisch versorgt und attached; es wird weder Leistung noch Drehmoment abgeschaltet.

Ein realer Betrieb braucht deshalb einen unabhaengigen, gut erreichbaren und verriegelnden Hardware-Leistungstrenner fuer den Servostrom. Dieser ist im Repository-Stand nicht vorhanden.

### Verhalten je Receiver-Modus

| Modus | Reaktion auf das Controller-Flag |
| --- | --- |
| Live-I2C | Receiver sendet `FRAME_FLAG_ESTOP`; der Arduino setzt neue Zielwerte auf seine Mittelpositionen und faehrt sie mit Slew-Limit an. Das ist kein sofortiges stromloses Stoppen. |
| committed Default `TEST_SWEEP` | Das Flag aendert LEDs/Status, der Sweep-Generator sendet aber weiter gueltige Bewegungsframes. Der GPIO21-Taster stoppt den Test-Sweep **nicht**. |

Vor jedem Einschalten muss deshalb bekannt sein, welcher Receiver-Build wirklich geflasht ist. Der committed Default ist `RECEIVER_MODE_TEST_SWEEP=1` und `RECEIVER_MODE_LIVE_I2C=0`; Live-Betrieb und jede Achse werden nur ueber explizite Compile-Flags freigegeben.

## Start-, Stop- und Rueckfallpose

Die aktive Arduino-Firmware verwendet die ganzzahligen Mittelpunkte der realen Grenzen. Sie verwendet nicht pauschal `90 Grad`.

| Gelenk | empirische Grenzen | Start / Timeout / Software-Stop |
| --- | --- | ---: |
| Basis | 12 bis 139 Grad | 75 Grad |
| Schulter | 35 bis 142 Grad | 88 Grad |
| Ellbogen | 80 bis 175 Grad | 127 Grad |
| Handgelenk | 5 bis 177 Grad | 91 Grad |
| Greifer | 32 bis 126 Grad | 79 Grad |

Diese Pose ist eine softwareseitige Mittelstellung, nicht nachgewiesen kollisionsfrei und nicht automatisch ergonomisch oder mechanisch lastfrei. Beim Attach kann die Arduino-Servo-Library kurz ihren Defaultpuls fuer `90 Grad` ausgeben, bevor der Sketch den jeweiligen Startwert schreibt. Servoenergie darf daher nicht in einer unkontrollierten oder kollisionsnahen Aufstellung zugeschaltet werden.

## Zeit- und Rampenverhalten

| Ebene | aktuelles Verhalten |
| --- | --- |
| Receiver Live-I2C | Paket aelter als `250 ms` fuehrt zu `FRAME_FLAG_NEUTRAL`. |
| Receiver Linkanzeige | Nach `2000 ms` ohne ESP-NOW-Paket wird ein Linkfehler angezeigt; dies ist allein keine Leistungsabschaltung. |
| Arduino | Nach `1000 ms` ohne gueltiges I2C-Frame werden die Mittelpositionen angefordert. |
| Arduino-Rampe | maximal `3 Grad` pro `20 ms`, rechnerisch bis etwa `150 Grad/s` je Achse. |
| Receiver-Rampe | pro 20-ms-Frame maximal 2 Byte fuer Basis/Schulter, 8 fuer Ellbogen/Handgelenk und 12 fuer Greifer. |

`ESTOP` und `NEUTRAL` springen nicht unmittelbar auf die Rueckfallpose; auch sie laufen durch die Arduino-Rampe. Fehlerhafte Magics, Versionen oder XOR-Werte werden verworfen. Die als `crc8` bezeichnete Pruefung ist technisch nur eine XOR-Pruefsumme und weder eine Safety-Garantie noch eine Authentisierung.

## Mechanische und regelungstechnische Grenzen

- Die Gelenkgrenzen sind empirische Prototypwerte, keine zertifizierten Sicherheitsgrenzen.
- Die Servos haben kein Positions-, Kraft- oder Stromfeedback. Die Software kennt weder reale Istposition noch Blockade oder externe Last.
- Der Realarm-Pfad nutzt Eulerwerte und pragmatische relative Abbildungen, keine vollstaendige Kinematik.
- Es gibt keinen nachgewiesenen Kollisionsschutz; der Dashboard-Solver ist kein Teil des Steuerpfads und ersetzt keinen realen Schutz.
- Den Arm niemals bei eingeschalteter Servoenergie von Hand erzwingen.
- Montage, Kabel, Perfboard und Wearable sind nicht auf Schweiss, Zug, Sturz, Dauerlast oder Alltagstauglichkeit freigegeben.

Die aktiven Grenzen und das Realarm-Mapping stehen in [`calibration/README.md`](calibration/README.md). Die reale Verdrahtung steht in [`docs/HARDWARE.md`](docs/HARDWARE.md#deutsch).

## Elektrisches I2C-Risiko

Der Receiver-ESP32 arbeitet mit `3.3 V`, das ATmega328P-Board mit `5 V`. SDA und SCL sind Open-Drain-Leitungen; vorhandene Pull-ups bestimmen den HIGH-Pegel. Ein Pull-up auf `5 V` kann den ESP32-S3 ausserhalb seines zulaessigen GPIO-Bereichs betreiben und beschaedigen.

Vor realer Bewegung muessen Pull-up-Ziel, Leerlaufpegel und gemeinsame Masse gemessen und dokumentiert werden. Die Leitungen muessen auf der ESP32-Seite auf `3.3 V` gezogen werden; bei `5 V` oder unbekannter Boardbeschaltung ist ein geeigneter bidirektionaler I2C-Levelshifter Pflicht. Bis dieser Nachweis vorliegt, ist die Verbindung `GPIO13/GPIO14 -> A4/A5` nicht elektrisch freigegeben. Details und Primaerquellen stehen in [`docs/HARDWARE.md`](docs/HARDWARE.md#de-i2c-pegel).

## Versorgung

- USB ist Upload-/Diagnosepfad und keine freigegebene Quelle fuer fuenf gleichzeitig aktive Servos.
- Servopfad und Logikpfade muessen definiert versorgt werden; gemeinsame Masse nur bewusst herstellen.
- Keine Versorgungen unbeabsichtigt ueber USB, Header oder Breadboard parallelschalten.
- Nur qualifizierte, unbeschaedigte 18650-Zellen paarweise mit gleichem Ladezustand verwenden und ausserhalb des Geraets in einem geeigneten Ladegeraet laden.
- Stromaufnahme, Sicherung, Kabelquerschnitt und Stecker sind fuer Dauerbetrieb noch nicht nachgewiesen.

## Mindestablauf vor Bewegung

1. Arm standsicher befestigen; Arbeitsraum, Quetschstellen und Anschlaege frei halten. Keine Person im Bewegungsraum.
2. Unabhaengigen Servostrom-Trenner erreichbar halten; Software-Stop nicht als einzige Schutzmassnahme verwenden.
3. I2C-Pegel nach [`docs/HARDWARE.md`](docs/HARDWARE.md#deutsch) verifizieren.
4. Geflashten Receiver-Modus und alle Achsenfreigaben ueber serielle Ausgabe pruefen. Test-Sweep nur in dafuer vorbereiteter, freier Aufstellung starten.
5. Zuerst ohne Servolast bzw. mit getrenntem Servostrom Kommunikation, Paketfrische und erwartete Zielwerte pruefen.
6. Beim ersten Zuschalten der Servoenergie mit kleinen, einzeln freigegebenen Bewegungen beginnen; jederzeit Hardware-Leistung trennen koennen.
7. Nach Reset, Reflash, Kabelwechsel, Kalibrierung oder mechanischem Umbau die Freigabe von vorn durchlaufen.

## Offene Freigabepunkte

- fail-safe Hardware-Not-Aus bzw. Servostrom-Trennung
- verifizierter 3.3-V-I2C-Pegel oder Levelshifter
- formale Tests fuer Boot, Stop, Timeout, Paketverlust und Wiederanlauf
- Last-, Blockier-, Dauerlauf- und Missbrauchstests
- dokumentierter Strompfad mit Absicherung
- Kollisions- und Quetschstellenbewertung
- Security-Haertung des Funkpfads; XOR ist kein Manipulationsschutz

Solange diese Punkte offen sind, bleibt der Arm ein beaufsichtigter Entwicklungsdemonstrator.

## Implementierungsquellen

- [Controller: GPIO21 und Startzustand](firmware/esp32_controller/esp32_controller.ino)
- [Receiver: Modi, Stale- und ESTOP-Abbildung](firmware/esp32_receiver/esp32_receiver.ino)
- [Arduino: Limits, Timeout und Slew](firmware/arduino_arm/arduino_arm.ino)
- [ESP32-S3 Series Datasheet](https://documentation.espressif.com/esp32_s3_datasheet_en.pdf)
- [Arduino UNO Rev3](https://store.arduino.cc/products/arduino-uno-rev3)

<div align="center">



</div>

---

# Safety

The robot arm can injure people and damage components. The current state is a tested `development prototype`, but it is neither safety-certified nor approved for unattended, industrial, medical, or any other safety-critical operation.

This file describes the actual behavior of the active firmware. Source-code approval is not operational approval.

## Most important limitation: no real emergency stop

The button on `GPIO21` is only a **software stop toggle**. It is not a `fail-safe` emergency stop and does not disconnect power:

- the controller explicitly initializes `notaus_aktiv` to `false` on every boot;
- because of `INPUT_PULLUP`, an open or disconnected input is HIGH and therefore starts **enabled**, not stopped;
- even a button held during boot does not reliably latch the stop, because only a later falling edge toggles the state;
- the state is transmitted as a flag over ESP-NOW and can be cleared again by a second button press;
- there is no redundant circuit, no forcibly guided contacts, no feedback circuit, and no dead-man path;
- the servos remain electrically powered and attached; neither power nor torque is removed.

Real operation therefore requires an independent, easily reachable, and latching hardware power disconnect for the servo supply. It is not present in the current repository state.

### Behavior by receiver mode

| Mode | Reaction to the controller flag |
| --- | --- |
| Live-I2C | The receiver sends `FRAME_FLAG_ESTOP`; the Arduino sets new targets to its midpoint positions and approaches them through the slew limit. This is not an immediate unpowered stop. |
| committed default `TEST_SWEEP` | The flag changes LEDs/status, but the sweep generator continues to send valid motion frames. The GPIO21 button does **not** stop the test sweep. |

Before every power-on, the receiver build that is actually flashed must therefore be known. The committed default is `RECEIVER_MODE_TEST_SWEEP=1` and `RECEIVER_MODE_LIVE_I2C=0`; live operation and every axis are enabled only through explicit compile flags.

## Start, stop, and fallback pose

The active Arduino firmware uses the integer midpoints of the real limits. It does not use a blanket `90 degrees` value.

| Joint | Empirical limits | Start / timeout / software stop |
| --- | --- | ---: |
| Base | 12 to 139 degrees | 75 degrees |
| Shoulder | 35 to 142 degrees | 88 degrees |
| Elbow | 80 to 175 degrees | 127 degrees |
| Wrist | 5 to 177 degrees | 91 degrees |
| Gripper | 32 to 126 degrees | 79 degrees |

This pose is a software midpoint position; it has not been proven collision-free and is not automatically ergonomic or mechanically unloaded. On attach, the Arduino Servo library may briefly output its default pulse for `90 degrees` before the sketch writes the respective start value. Servo power must therefore not be switched on while the arm is in an uncontrolled or near-collision setup.

## Timing and ramp behavior

| Layer | Current behavior |
| --- | --- |
| Receiver Live-I2C | A packet older than `250 ms` leads to `FRAME_FLAG_NEUTRAL`. |
| Receiver link indication | After `2000 ms` without an ESP-NOW packet, a link error is indicated; this alone does not disconnect power. |
| Arduino | After `1000 ms` without a valid I2C frame, the midpoint positions are requested. |
| Arduino ramp | maximum `3 degrees` per `20 ms`, mathematically up to about `150 degrees/s` per axis. |
| Receiver ramp | per 20 ms frame, at most 2 bytes for base/shoulder, 8 for elbow/wrist, and 12 for gripper. |

`ESTOP` and `NEUTRAL` do not jump immediately to the fallback pose; they also pass through the Arduino ramp. Frames with invalid magic values, versions, or XOR values are discarded. The check named `crc8` is technically only an XOR checksum and provides neither a safety guarantee nor authentication.

## Mechanical and control-system limitations

- The joint limits are empirical prototype values, not certified safety limits.
- The servos have no position, force, or current feedback. The software knows neither the actual position nor a stall or external load.
- The real-arm path uses Euler values and pragmatic relative mappings, not complete kinematics.
- There is no proven collision protection; the dashboard solver is not part of the control path and does not replace real protection.
- Never force the arm by hand while servo power is enabled.
- The mounting, cables, perfboard, and wearable are not approved for sweat, pulling, falls, continuous load, or everyday use.

The active limits and real-arm mapping are documented in [`calibration/README.md`](calibration/README.md). The actual wiring is documented in [`docs/HARDWARE.md`](docs/HARDWARE.md#english).

## Electrical I2C risk

The receiver ESP32 operates at `3.3 V`, while the ATmega328P board operates at `5 V`. SDA and SCL are open-drain lines; the installed pull-ups determine the HIGH level. A pull-up to `5 V` can operate the ESP32-S3 outside its permitted GPIO range and damage it.

Before real motion, the pull-up target, idle level, and common ground must be measured and documented. The lines must be pulled to `3.3 V` on the ESP32 side; with `5 V` or unknown board wiring, a suitable bidirectional I2C level shifter is mandatory. Until this evidence exists, the `GPIO13/GPIO14 -> A4/A5` connection is not electrically approved. Details and primary sources are provided in [`docs/HARDWARE.md`](docs/HARDWARE.md#en-i2c-levels).

## Power supply

- USB is an upload/diagnostic path and is not an approved source for five simultaneously active servos.
- The servo path and logic paths must have defined supplies; establish a common ground only deliberately.
- Do not unintentionally parallel power supplies through USB, headers, or a breadboard.
- Use only qualified, undamaged 18650 cells in matched pairs at the same state of charge, and charge them outside the device in a suitable charger.
- Current draw, fuse protection, cable cross-section, and connectors have not yet been demonstrated for continuous operation.

## Minimum procedure before motion

1. Secure the arm so it is stable; keep the workspace, pinch points, and stops clear. No person may be inside the motion area.
2. Keep an independent servo-power disconnect within reach; do not use the software stop as the only protective measure.
3. Verify the I2C levels according to [`docs/HARDWARE.md`](docs/HARDWARE.md#english).
4. Check the flashed receiver mode and every axis enable through serial output. Start the test sweep only in a prepared, unobstructed setup.
5. First verify communication, packet freshness, and expected targets without servo load or with servo power disconnected.
6. When enabling servo power for the first time, begin with small movements and individually enabled axes; hardware power must remain disconnectable at all times.
7. After a reset, reflash, cable change, calibration, or mechanical modification, repeat the approval procedure from the beginning.

## Open approval items

- fail-safe hardware emergency stop or servo-power disconnect
- verified 3.3 V I2C level or level shifter
- formal tests for boot, stop, timeout, packet loss, and restart
- load, stall, endurance, and misuse tests
- documented power path with protection
- collision and pinch-point assessment
- security hardening of the radio path; XOR does not protect against manipulation

As long as these items remain open, the arm remains a supervised development demonstrator.

## Implementation sources

- [Controller: GPIO21 and initial state](firmware/esp32_controller/esp32_controller.ino)
- [Receiver: modes, stale-data, and ESTOP mapping](firmware/esp32_receiver/esp32_receiver.ino)
- [Arduino: limits, timeout, and slew](firmware/arduino_arm/arduino_arm.ino)
- [ESP32-S3 Series Datasheet](https://documentation.espressif.com/esp32_s3_datasheet_en.pdf)
- [Arduino UNO Rev3](https://store.arduino.cc/products/arduino-uno-rev3)

<div align="center">



</div>

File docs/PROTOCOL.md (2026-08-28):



<div align="center">




</div>

---

# Kommunikationsprotokolle

Dieses Dokument trennt den bewegungsrelevanten Steuerpfad vom Debug-/Twin-Pfad und beschreibt den aktuell implementierten Stand. Checksummen erkennen einfache Uebertragungsfehler; sie sind keine Authentisierung und keine Security-Grenze.

## Pfade und Verantwortungen

```text
Steuerpfad:
3x BNO055 + Potentiometer
  -> Controller
  -> ESP-NOW
  -> Receiver
  -> I2C
  -> Arduino
  -> 5 Servos

Debug-/Twin-Pfad:
Controller
  -> zweiter ESP-NOW-Peer
  -> Bridge
  -> WiFi / MQTT
  -> Dashboard, MCP und ROS 2
```

Die Bridge ist ein aktiver, separat betreibbarer Debugbestandteil. Sie liegt nicht in Reihe mit dem Steuerpfad; ihr Ausfall darf die Receiver-/Arduino-Kette nicht unterbrechen. Ob der Controller den zweiten Peer sendet, bestimmt die lokale Einstellung `BRIDGE_AKTIV`.

## ESP-NOW: `ImuPaket v4`

Controller, Receiver und Bridge verwenden dieselbe gepackte Struktur:

| Feld | Typ | Bedeutung |
| --- | --- | --- |
| `zaehler` | `uint32_t` | monotoner Paketzaehler innerhalb einer Controller-Laufzeit |
| `sensoren[3]` | je 3 `float` | `heading`, `roll`, `pitch` |
| `kalib[3]` | je 4 `uint8_t` | `sys`, `gyro`, `accel`, `mag` |
| `flex_prozent` | `float` | aktueller Potentiometer-Greiferwert; MQTT-Schluessel bleibt kompatibel `f` |
| `flags` | `uint8_t` | Bit 0: Software-Notaus; Bits 1-7 reserviert |
| `protokoll_version` | `uint8_t` | Wert `4` |
| `pruefsumme` | `uint8_t` | XOR ueber alle vorherigen Paketbytes |

Segmentzuordnung: `S0 = Hand/Wrist`, `S1 = Unterarm`, `S2 = Oberarm`. Der Controller zielt nominell auf ein Sendeintervall von 5 ms und sendet per Unicast auf WiFi-Kanal 1. Receiver und Controller setzen Kanal 1 explizit; der WiFi-Access-Point der Bridge muss deshalb ebenfalls auf Kanal 1 liegen.

Der aktuelle Funkpfad ist nicht kryptografisch gehaertet:

- die Controller-Peers verwenden `encrypt=false`;
- der Receiver prueft Laenge, Protokollversion, XOR-Pruefsumme und einen steigenden Zaehler, aber nicht die Quell-MAC aus dem Empfangs-Callback;
- nach 2 s Link-Timeout setzt der Receiver seine Zaehlerannahme zurueck;
- die Bridge prueft zusaetzlich die lokal konfigurierte Controller-MAC;
- `session_id`, Authentisierungstag und belastbarer Replay-Schutz sind nicht implementiert.

Die Implementierungen liegen im [Controller](../firmware/esp32_controller/esp32_controller.ino), [Receiver](../firmware/esp32_receiver/esp32_receiver.ino) und in der [Bridge](../firmware/esp32_bridge/esp32_bridge.ino).

## Receiver-Modi und Frische

Der committed und gebaute Default lautet:

```text
RECEIVER_MODE_TEST_SWEEP=1
RECEIVER_MODE_LIVE_I2C=0
RECEIVER_LIVE_ENABLE_BASIS=0
RECEIVER_LIVE_ENABLE_SHOULDER=0
RECEIVER_LIVE_ENABLE_ELBOW=0
RECEIVER_LIVE_ENABLE_WRIST=0
RECEIVER_LIVE_ENABLE_GRIPPER=0
RECEIVER_I2C_SEND_ENABLED=1
```

Der real getestete Livepfad wird nur mit den dokumentierten Compile-Flags aus [`BUILD.md`](BUILD.md#deutsch) aktiviert. Im Live-Modus gilt:

- 20 ms I2C-Intervall, also 50 Hz Zielrate;
- ein ESP-NOW-Paket ist nach 250 ms ohne Aktualisierung stale und erzeugt einen Neutral-Frame;
- Software-Notaus erzeugt einen E-Stop-Frame;
- der ESP-NOW-Callback validiert und puffert nur; I2C-Ausgabe und serielle Diagnose laufen im `loop()`;
- Receiver-Slew pro Frame: Basis/Schulter 2 Byte, Ellbogen/Handgelenk 8 Byte, Greifer 12 Byte;
- deaktivierte Achsen laufen gegen den neutralen Bytewert 128.

Der zusaetzliche 2-s-`EMPFANGS_TIMEOUT` steuert Link-/Fehleranzeige und setzt die Paketzaehlerannahme zurueck. Fuer die Bewegung greift im Live-Modus bereits die 250-ms-Stale-Regel.

## I2C Frame V1

Transport: ESP32-Receiver als Master auf `GPIO13`/`GPIO14`, 100 kHz; Arduino als Slave `0x42` auf `A4`/`A5`. Die elektrische Pegelfreigabe wird separat in [`HARDWARE.md`](HARDWARE.md#de-receiver-arduino-i2c) behandelt.

Das Frame ist immer 11 Byte lang:

| Byte | Feld | Bedeutung |
| ---: | --- | --- |
| 0 | `start_a` | `0xA5` |
| 1 | `start_b` | `0x5A` |
| 2 | `protokoll_version` | `1` |
| 3 | `sequenz` | `uint8_t`, Ueberlauf 255 -> 0 |
| 4 | `flags` | Statusbits |
| 5 | `basis_soll` | 0-255 |
| 6 | `schulter_soll` | 0-255 |
| 7 | `ellbogen_soll` | 0-255 |
| 8 | `handgelenk_soll` | 0-255 |
| 9 | `greifer_soll` | 0-255 |
| 10 | `pruefsumme` | XOR ueber Byte 0-9 |

Flags: Bit 0 `VALID`, Bit 1 `NEUTRAL`, Bit 2 `DEGRADED`, Bit 3 `ESTOP`; Bit 4-7 sind reserviert. Feld- und Funktionsnamen im Quellcode heissen aus historischen Gruenden teilweise noch `crc8`. Der implementierte Algorithmus ist jedoch nur eine XOR-Pruefsumme, keine CRC-8.

Der Arduino prueft Startbytes, Version und XOR. `VALID` mappt die fuenf Bytewerte auf die empirischen Servolimits. `NEUTRAL` und `ESTOP` setzen dieselben Mittelwertziele; die Bewegung dorthin bleibt durch den Arduino-Slew von maximal 3 Grad pro 20-ms-Zyklus begrenzt. Die Neutralziele sind `75/88/127/91/79` Grad fuer Basis/Schulter/Ellbogen/Handgelenk/Greifer, nicht pauschal 90 Grad. Nach 1 s ohne gueltiges Frame setzt der Arduino ebenfalls diese Ziele. Das ist ein Software-Rueckfallverhalten und keine elektrische Leistungsabschaltung.

Quelle fuer Sender und Empfaenger: [`i2c_frame.h`](../firmware/esp32_receiver/i2c_frame.h) und [`arduino_arm.ino`](../firmware/arduino_arm/arduino_arm.ino).

## MQTT ist nicht ROS

Die Bridge publiziert diese MQTT-Topics:

| MQTT-Topic | Inhalt | Verhalten |
| --- | --- | --- |
| `robotarm/imu` | Paketzaehler, drei IMUs, Kalibrierstatus, `f`, Flags, Notaus, Version | pro weitergeleitetem Paket, nicht retained |
| `robotarm/status` | RSSI, Uptime, Paket-/Fehlerzaehler, Rate, Notaus | etwa 1 Hz, retained |
| `robotarm/kalib` | Kalibrierstatus aller drei Sensoren | bei Aenderung, retained |
| `robotarm/ota/log` | OTA-Ereignisse der Bridge | bei Ereignis, nicht retained |

ROS 2 konsumiert standardmaessig nur MQTT `robotarm/imu` und publiziert danach lokale ROS-Schnittstellen:

| ROS-Schnittstelle | Typ/Zweck |
| --- | --- |
| `/joint_states` | gemappte Gelenkstaende fuer RViz/Twin |
| `/robotarm/debug/raw_imu` | optionaler ROS-Debugstream mit MQTT-Rohpayload |
| `/robotarm/debug/mapping` | optionaler ROS-Debugstream mit Mappingdetails |
| `/toggle_arm` | lokaler ROS-Service fuer die Twin-Anzeige `front/back/both` |

Die Pfade `/robotarm/debug/raw_imu` und `/robotarm/debug/mapping` sind ROS-Topics, keine von der ESP32-Bridge publizierten MQTT-Topics. Keiner dieser Debug-/Twin-Pfade speist im aktuellen Stand Bewegungsziele in Receiver oder Arduino ein.

Security-Grenzen und Publish-Rechte stehen in [`SECURITY.md`](../SECURITY.md#deutsch); Nachweise und offene Tests in [`TESTING.md`](TESTING.md#deutsch).

<div align="center">



</div>

---

# Communication protocols

This document separates the motion-relevant control path from the debug/twin
path and describes the currently implemented state. Checksums detect simple
transmission errors; they are neither authentication nor a security boundary.

## Paths and responsibilities

```text
Control path:
3x BNO055 + potentiometer
  -> Controller
  -> ESP-NOW
  -> Receiver
  -> I2C
  -> Arduino
  -> 5 servos

Debug/twin path:
Controller
  -> second ESP-NOW peer
  -> Bridge
  -> WiFi / MQTT
  -> Dashboard, MCP, and ROS 2
```

The bridge is an active debug component that can be operated independently. It
is not in series with the control path, and its failure must not interrupt the
receiver/Arduino chain. The local `BRIDGE_AKTIV` setting determines whether the
controller transmits to the second peer.

## ESP-NOW: `ImuPaket v4`

The controller, receiver, and bridge use the same packed structure:

| Field | Type | Meaning |
| --- | --- | --- |
| `zaehler` | `uint32_t` | monotonically increasing packet counter within one controller runtime |
| `sensoren[3]` | three `float` values each | `heading`, `roll`, `pitch` |
| `kalib[3]` | four `uint8_t` values each | `sys`, `gyro`, `accel`, `mag` |
| `flex_prozent` | `float` | current potentiometer-based gripper value; the MQTT key remains `f` for compatibility |
| `flags` | `uint8_t` | bit 0: software E-stop; bits 1-7 reserved |
| `protokoll_version` | `uint8_t` | value `4` |
| `pruefsumme` | `uint8_t` | XOR across all preceding packet bytes |

Segment assignment: `S0 = hand/wrist`, `S1 = forearm`, `S2 = upper arm`. The
controller nominally targets a 5 ms transmission interval and sends unicast on
WiFi channel 1. The receiver and controller set channel 1 explicitly, so the
bridge's WiFi access point must also use channel 1.

The current radio path is not cryptographically hardened:

- the controller peers use `encrypt=false`;
- the receiver validates length, protocol version, XOR checksum, and an
  increasing counter, but it does not validate the source MAC from the receive
  callback;
- after a 2 s link timeout, the receiver resets its counter assumption;
- the bridge additionally validates the locally configured controller MAC;
- `session_id`, an authentication tag, and robust replay protection are not
  implemented.

The implementations are in the [controller](../firmware/esp32_controller/esp32_controller.ino), [receiver](../firmware/esp32_receiver/esp32_receiver.ino), and [bridge](../firmware/esp32_bridge/esp32_bridge.ino).

## Receiver modes and freshness

The committed and compiled default is:

```text
RECEIVER_MODE_TEST_SWEEP=1
RECEIVER_MODE_LIVE_I2C=0
RECEIVER_LIVE_ENABLE_BASIS=0
RECEIVER_LIVE_ENABLE_SHOULDER=0
RECEIVER_LIVE_ENABLE_ELBOW=0
RECEIVER_LIVE_ENABLE_WRIST=0
RECEIVER_LIVE_ENABLE_GRIPPER=0
RECEIVER_I2C_SEND_ENABLED=1
```

The physically tested live path is enabled only with the documented compile
flags from [`BUILD.md`](BUILD.md#english). In live mode:

- the I2C interval is 20 ms, for a 50 Hz target rate;
- an ESP-NOW packet becomes stale after 250 ms without an update and produces a
  neutral frame;
- the software E-stop produces an E-stop frame;
- the ESP-NOW callback only validates and buffers data; I2C output and serial
  diagnostics run in `loop()`;
- receiver slew per frame: 2 bytes for base/shoulder, 8 bytes for elbow/wrist,
  and 12 bytes for the gripper;
- disabled axes move toward the neutral byte value 128.

The additional 2 s `EMPFANGS_TIMEOUT` controls the link/fault indication and
resets the packet-counter assumption. In live mode, motion already uses the
250 ms stale rule.

## I2C Frame V1

Transport: ESP32 receiver as master on `GPIO13`/`GPIO14` at 100 kHz; Arduino as
slave `0x42` on `A4`/`A5`. Electrical level approval is handled separately in
[`HARDWARE.md`](HARDWARE.md#en-receiver-arduino-i2c).

The frame is always 11 bytes long:

| Byte | Field | Meaning |
| ---: | --- | --- |
| 0 | `start_a` | `0xA5` |
| 1 | `start_b` | `0x5A` |
| 2 | `protokoll_version` | `1` |
| 3 | `sequenz` | `uint8_t`, wraps from 255 -> 0 |
| 4 | `flags` | status bits |
| 5 | `basis_soll` | 0-255 |
| 6 | `schulter_soll` | 0-255 |
| 7 | `ellbogen_soll` | 0-255 |
| 8 | `handgelenk_soll` | 0-255 |
| 9 | `greifer_soll` | 0-255 |
| 10 | `pruefsumme` | XOR across bytes 0-9 |

Flags: bit 0 `VALID`, bit 1 `NEUTRAL`, bit 2 `DEGRADED`, bit 3 `ESTOP`; bits
4-7 are reserved. Some fields and functions in the source code retain the
historical name `crc8`, but the implemented algorithm is only an XOR checksum,
not CRC-8.

The Arduino validates the start bytes, version, and XOR. `VALID` maps the five
byte values to the empirical servo limits. `NEUTRAL` and `ESTOP` set the same
midpoint targets; motion toward them remains limited by the Arduino slew of at
most 3 degrees per 20 ms cycle. The neutral targets are `75/88/127/91/79`
degrees for base/shoulder/elbow/wrist/gripper, not a uniform 90 degrees. After
1 s without a valid frame, the Arduino also requests these targets. This is
software fallback behavior, not an electrical power cutoff.

The sender and receiver sources are [`i2c_frame.h`](../firmware/esp32_receiver/i2c_frame.h) and [`arduino_arm.ino`](../firmware/arduino_arm/arduino_arm.ino).

## MQTT is not ROS

The bridge publishes these MQTT topics:

| MQTT topic | Content | Behavior |
| --- | --- | --- |
| `robotarm/imu` | packet counter, three IMUs, calibration status, `f`, flags, E-stop, version | once per forwarded packet, not retained |
| `robotarm/status` | RSSI, uptime, packet/error counters, rate, E-stop | approximately 1 Hz, retained |
| `robotarm/kalib` | calibration status for all three sensors | on change, retained |
| `robotarm/ota/log` | bridge OTA events | on event, not retained |

By default, ROS 2 consumes only the MQTT topic `robotarm/imu` and then publishes
local ROS interfaces:

| ROS interface | Type/purpose |
| --- | --- |
| `/joint_states` | mapped joint states for RViz/twin |
| `/robotarm/debug/raw_imu` | optional ROS debug stream carrying the raw MQTT payload |
| `/robotarm/debug/mapping` | optional ROS debug stream with mapping details |
| `/toggle_arm` | local ROS service for the twin display modes `front/back/both` |

The paths `/robotarm/debug/raw_imu` and `/robotarm/debug/mapping` are ROS topics,
not MQTT topics published by the ESP32 bridge. In the current state, none of
these debug/twin paths injects motion targets into the receiver or Arduino.

Security boundaries and publish permissions are documented in
[`SECURITY.md`](../SECURITY.md#english); evidence and pending tests are documented in
[`TESTING.md`](TESTING.md#english).

<div align="center">



</div>

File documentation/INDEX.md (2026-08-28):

# Dokumentationsindex

Erzeugt am: 2026-08-28 03:41:36 GMT

## Markdown-Dokumente

- [AGENTS.md](snapshot/AGENTS.md)
- [LICENSE.md](snapshot/LICENSE.md)
- [README.md](snapshot/README.md)
- [ROADMAP.md](snapshot/ROADMAP.md)
- [SAFETY.md](snapshot/SAFETY.md)
- [SECURITY.md](snapshot/SECURITY.md)
- [calibration/README.md](snapshot/calibration/README.md)
- [calibration/reference_poses/README.md](snapshot/calibration/reference_poses/README.md)
- [calibration/servo_limits/README.md](snapshot/calibration/servo_limits/README.md)
- [dashboard/DASHBOARD_CONCEPT.md](snapshot/dashboard/DASHBOARD_CONCEPT.md)
- [dashboard/README.md](snapshot/dashboard/README.md)
- [docs/BUILD.md](snapshot/docs/BUILD.md)
- [docs/HARDWARE.md](snapshot/docs/HARDWARE.md)
- [docs/PROTOCOL.md](snapshot/docs/PROTOCOL.md)
- [docs/TESTING.md](snapshot/docs/TESTING.md)
- [docs/measurement_logs/README.md](snapshot/docs/measurement_logs/README.md)
- [docs/photos/README.md](snapshot/docs/photos/README.md)
- [docs/photos/readme/README.md](snapshot/docs/photos/readme/README.md)
- [firmware/I2C_FRAME_V1.md](snapshot/firmware/I2C_FRAME_V1.md)
- [firmware/README.md](snapshot/firmware/README.md)
- [firmware/SERVO_UART_DESIGNENTSCHEIDUNGEN.md](snapshot/firmware/SERVO_UART_DESIGNENTSCHEIDUNGEN.md)
- [firmware/UART_FRAME_V1.md](snapshot/firmware/UART_FRAME_V1.md)
- [firmware/archive/README.md](snapshot/firmware/archive/README.md)
- [hardware/electronics/SCHEMATIC_CURRENT.md](snapshot/hardware/electronics/SCHEMATIC_CURRENT.md)
- [memory/project_servo_pin_mapping.md](snapshot/memory/project_servo_pin_mapping.md)
- [official_downloads/README.md](snapshot/official_downloads/README.md)
- [ros2/README.md](snapshot/ros2/README.md)
- [tests/README.md](snapshot/tests/README.md)

## Gespiegelte Medien

- [docs/photos/readme/2026-05-10_robotarm_live_demo.gif](snapshot/docs/photos/readme/2026-05-10_robotarm_live_demo.gif)
- [docs/photos/readme/20260423_213652000-ios.gif](snapshot/docs/photos/readme/20260423_213652000-ios.gif)
- [docs/photos/readme/ros-2.gif](snapshot/docs/photos/readme/ros-2.gif)
- [dashboard/web/screenshots/01_live_daten.png](snapshot/dashboard/web/screenshots/01_live_daten.png)
- [dashboard/web/screenshots/02_statistiken.png](snapshot/dashboard/web/screenshots/02_statistiken.png)
- [dashboard/web/screenshots/03_3d_modell.png](snapshot/dashboard/web/screenshots/03_3d_modell.png)
- [dashboard/web/screenshots/04_debug_konsole.png](snapshot/dashboard/web/screenshots/04_debug_konsole.png)

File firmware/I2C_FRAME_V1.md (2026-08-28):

# I2C Frame V1

Dieses Dokument bleibt als stabiles Ziel fuer Verweise im aktiven Quellcode
erhalten. Die uebergreifende Protokollbeschreibung steht in
[`docs/PROTOCOL.md`](../docs/PROTOCOL.md).

## Transport

- ESP32-S3 Receiver als Master: SDA GPIO13, SCL GPIO14
- Arduino Uno als Slave: SDA A4, SCL A5, Adresse `0x42`
- Standard-Mode mit 100 kHz
- 11 Byte pro Frame, ohne Padding

Wegen der moeglichen 5-V-Pull-ups auf der Arduino-Seite muss vor dem Betrieb
am ESP32 ein High-Pegel von hoechstens 3,6 V nachgewiesen oder ein geeigneter
bidirektionaler Pegelwandler eingesetzt werden. Details stehen in
[`docs/HARDWARE.md`](../docs/HARDWARE.md) und [`SAFETY.md`](../SAFETY.md).

## Frame

| Byte | Feld | Wert oder Bedeutung |
| ---: | --- | --- |
| 0 | `start_a` | `0xA5` |
| 1 | `start_b` | `0x5A` |
| 2 | `protokoll_version` | `1` |
| 3 | `sequenz` | `uint8_t`, Ueberlauf ist erlaubt |
| 4 | `flags` | Bitfeld |
| 5 | `basis_soll` | `0..255` |
| 6 | `schulter_soll` | `0..255` |
| 7 | `ellbogen_soll` | `0..255` |
| 8 | `handgelenk_soll` | `0..255` |
| 9 | `greifer_soll` | `0..255` |
| 10 | `crc8` | XOR der Bytes 0 bis 9 |

`crc8` ist der historische Feld- und Funktionsname. Implementiert ist eine
einfache XOR-Pruefsumme, kein CRC-8-Verfahren.

## Flags und Verhalten

| Bit | Name | Bedeutung |
| ---: | --- | --- |
| 0 | `VALID` | Achswerte anwenden |
| 1 | `NEUTRAL` | definierte Mittelziele anfordern |
| 2 | `DEGRADED` | eingeschraenkte Datenqualitaet melden |
| 3 | `ESTOP` | Software-Notaus-Ziel anfordern |
| 4..7 | reserviert | nicht verwenden |

Neutral und Software-Notaus setzen die Servo-Ziele auf
`75/88/127/91/79` Grad und fahren sie mit der vorhandenen Slew-Begrenzung an.
Sie trennen weder Versorgung noch Drehmoment und ersetzen keinen physischen
Not-Halt.

## Implementierungen

- Sender: [`esp32_receiver/i2c_frame.h`](esp32_receiver/i2c_frame.h)
- Empfaenger: [`arduino_arm/arduino_arm.ino`](arduino_arm/arduino_arm.ino)
- Hardware- und Timingbegruendung:
  [`SERVO_UART_DESIGNENTSCHEIDUNGEN.md`](SERVO_UART_DESIGNENTSCHEIDUNGEN.md)

Die Structs auf beiden Seiten muessen bytegenau identisch bleiben. Der
eingecheckte Receiver-Default ist der Test-Sweep; Live-I2C und einzelne Achsen
werden bewusst ueber Compile-Flags freigeschaltet.

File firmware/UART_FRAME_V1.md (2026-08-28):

# UART Frame V1 (archiviert)

Diese Spezifikation gehoert zum historischen UART-Pfad unter
[`firmware/archive/uart/`](archive/uart/). Der aktive Receiver-Arduino-Pfad
verwendet I2C; siehe [`I2C_FRAME_V1.md`](I2C_FRAME_V1.md) und die kanonische
Beschreibung in [`docs/PROTOCOL.md`](../docs/PROTOCOL.md).

## Transport

- ESP32 Hardware-UART TX: GPIO15, `9600 8N1`
- Arduino SoftwareSerial RX: D2
- Einwegverbindung vom Receiver zum Arduino
- 11 Byte pro Frame, ohne Padding

## Frame

| Byte | Feld | Wert oder Bedeutung |
| ---: | --- | --- |
| 0 | `start_a` | `0xA5` |
| 1 | `start_b` | `0x5A` |
| 2 | `protokoll_version` | `1` |
| 3 | `sequenz` | `uint8_t`, Ueberlauf ist erlaubt |
| 4 | `flags` | Bitfeld |
| 5 | `basis_soll` | `0..255` |
| 6 | `schulter_soll` | `0..255` |
| 7 | `ellbogen_soll` | `0..255` |
| 8 | `handgelenk_soll` | `0..255` |
| 9 | `greifer_soll` | `0..255` |
| 10 | `crc8` | XOR der Bytes 0 bis 9 |

`crc8` ist der historische Feld- und Funktionsname. Implementiert ist eine
einfache XOR-Pruefsumme, kein CRC-8-Verfahren.

Flags: Bit 0 = gueltig, Bit 1 = Neutralziel, Bit 2 = degraded, Bit 3 =
Software-Notaus. Neutral und Software-Notaus setzen nur Servo-Zielwerte; sie
trennen weder Versorgung noch Drehmoment.

Implementierungen:

- [`uart_frame.h`](archive/uart/esp32_receiver_legacy_uart/uart_frame.h)
- [`arduino_arm_uart.ino`](archive/uart/arduino_arm_uart.ino)

Der UART-Pfad ist nur zur Nachvollziehbarkeit archiviert und nicht Teil des
aktuellen Build- oder Flashpfads.

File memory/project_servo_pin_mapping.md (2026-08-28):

# Servo-Pin-Zuordnung

Diese Datei bleibt als stabiles Ziel fuer Verweise im aktiven und archivierten
Arduino-Sketch erhalten. Die kanonische Hardwarebeschreibung steht in
[`docs/HARDWARE.md`](../docs/HARDWARE.md).

| Gelenk | Arduino-Pin | zugeordneter Poti-Eingang |
| --- | ---: | ---: |
| Basis | D9 | A0 |
| Greifer | D6 | A1 |
| Handgelenk | D5 | A2 |
| Ellbogen | D3 | A3 |
| Schulter | D11 | A6 |

Diese empirisch ermittelte Zuordnung weicht vom Herstellerbeispiel ab. Eine
Aenderung erfordert eine erneute Pruefung an der realen Verkabelung.

Gemessene Winkelgrenzen und sichere Zielwerte stehen in
[`calibration/servo_limits/README.md`](../calibration/servo_limits/README.md).

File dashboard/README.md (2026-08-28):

# Dashboard und MQTT-MCP

Dieses Verzeichnis enthaelt den beobachtenden Browser-Twin und den optionalen
MQTT-MCP-Server. Beide nutzen den Debugpfad; sie sind nicht Teil des
sicherheitskritischen Steuerpfads zum realen Arm.

```text
Steuerpfad: Controller --ESP-NOW--> Receiver --I2C--> Arduino --> Servos
Debugpfad:  Controller --ESP-NOW--> Bridge --MQTT--> Dashboard / MCP / ROS 2
```

Ein Ausfall oder eine falsche Anzeige im Debugpfad darf die Armsteuerung nicht
beeinflussen. Der Twin ist ein Diagnosewerkzeug und keine Safety-Freigabe.

## Inhalt

| Pfad | Aufgabe |
| --- | --- |
| `web/views/robotarm.php` | Einbindbares HTML/PHP-Fragment mit vier Unteransichten |
| `web/js/robotarm.js` | MQTT-over-WebSocket, Livewerte, Statistik, Charts und Konsole |
| `web/js/robotarm_3d.js` | Three.js-Szene und Twin-Mapping |
| `web/css/robotarm.css` | Robotarm-spezifische Styles |
| `web/screenshots/` | Screenshots des verifizierten Stands |
| `mcp/mqtt_mcp_server.py` | MCP-Server fuer MQTT-Lesen und optionales Test-Publizieren |
| `mcp/*.template.*` | Vorlagen ohne echte Zugangsdaten |

Die Dateien unter `web/` sind Module des bestehenden IoT Control Centers und
kein eigenstaendiger Webserver.

## MQTT-Schnittstelle

Die Bridge-Firmware publiziert genau diese Topics:

| MQTT-Topic | Inhalt | Verhalten |
| --- | --- | --- |
| `robotarm/imu` | `ImuPaket v4` als JSON | bei jedem validen Bridge-Paket |
| `robotarm/status` | RSSI, Uptime, Paket-/Fehlerzaehler, Rate, Notaus | etwa 1 Hz, retained |
| `robotarm/kalib` | Kalibrierwerte der drei BNO055 | bei Aenderung, retained |
| `robotarm/ota/log` | Start, Erfolg oder Fehler eines Bridge-OTA-Vorgangs | ereignisgesteuert |

Das Dashboard wertet `robotarm/imu`, `robotarm/status` und `robotarm/kalib`
gezielt aus. Seine Konsole zeigt alle abonnierten `robotarm/#`-Nachrichten.

Der IMU-Payload verwendet folgende Kurzschluessel:

| Schluessel | Bedeutung |
| --- | --- |
| `z` | Paketzaehler |
| `s[0..2]` | Hand, Unterarm, Oberarm mit `h`, `r`, `p` |
| `k[0..2]` | BNO055-Status `s`, `g`, `a`, `m` |
| `f` | aktueller Potentiometer-basierter Greiferwert in Prozent |
| `fl` | Flags; Bit 0 ist der Software-Notaus-Status |
| `notaus` | aus Bit 0 abgeleiteter boolescher Anzeigewert |
| `v` | Protokollversion, aktuell `4` |

Wichtig: `/joint_states`, `/robotarm/debug/raw_imu` und
`/robotarm/debug/mapping` sind **ROS-2-Topics**, keine MQTT-Topics. Sie werden
erst lokal von `ros2/` erzeugt und sind nicht im MQTT-WebSocket sichtbar.

## Browser-Modul integrieren

Vorausgesetzt werden ein Mosquitto-WebSocket-Listener hinter `/mqtt`, der
bereits vorhandene Nginx/Webserver und diese Browser-Bibliotheken:

- `mqtt.js` als `window.mqtt`
- `Chart.js` als `window.Chart`
- `Three.js` als `window.THREE`

Vor `web/js/robotarm.js` muss die Host-Anwendung die JavaScript-Globals
`MQTT_WS_USER`, `MQTT_WS_PASS` und `MQTT_WS_TOPICS` definieren. Der verwendete
Broker-Account soll nur `robotarm/#` lesen duerfen. Zugangsdaten gehoeren in
die lokale Serverkonfiguration, nicht in dieses Repository.

Deployment auf dem Pi:

```text
web/views/robotarm.php -> /var/www/html/views/robotarm.php
web/js/robotarm.js     -> /var/www/html/js/robotarm.js
web/js/robotarm_3d.js  -> /var/www/html/js/robotarm_3d.js
web/css/robotarm.css   -> /var/www/html/css/robotarm.css
```

Die Host-Anwendung muss das View-Fragment einbinden, CSS und Skripte laden und
beim Oeffnen des Tabs `raOnTabActivate()` aufrufen. Die `data-click`-Attribute
im Fragment setzen den vorhandenen Event-Dispatcher des IoT Control Centers
voraus. Das Dashboard selbst publiziert keine MQTT-Nachrichten.

## MQTT-MCP-Server

Der MCP-Server laeuft per `stdio` und braucht Python, `paho-mqtt` und das
Python-Paket `mcp`:

```bash
cd dashboard/mcp
python3 -m venv "$HOME/.venvs/robotarm-mcp"
. "$HOME/.venvs/robotarm-mcp/bin/activate"
python3 -m pip install paho-mqtt mcp
cp mqtt_config.template.py mqtt_config.local.py
chmod 600 mqtt_config.local.py
python3 mqtt_mcp_server.py
```

`mqtt_config.local.py` ist gitignoriert. Der Prozess stellt sechs Werkzeuge
bereit:

| Werkzeug | Wirkung |
| --- | --- |
| `mqtt_subscribe` | wartet auf eine konfigurierbare Anzahl Nachrichten |
| `mqtt_read_latest` | liest den letzten lokal empfangenen Wert |
| `mqtt_list_topics` | listet seit Prozessstart beobachtete Topics |
| `mqtt_history` | liest bis zu 100 lokal gepufferte Nachrichten |
| `mqtt_status` | zeigt Verbindung und Empfangsstatistik |
| `mqtt_publish` | publiziert auf beliebige Topics mit Praefix `robotarm/` |

Der MCP-Code ist damit **nicht intrinsisch read-only**. Die mitgelieferte
`mosquitto_acl.template.conf` gibt `mcp_reader` nur Leserechte; dann weist der
Broker Publish-Versuche ab. Falls Test-Publizieren wirklich benoetigt wird,
soll dafuer ein separater Account mit einem engen Test-Topic verwendet werden,
nicht pauschal Schreibrecht auf `robotarm/#`.

`ota_config.template.py` ist derzeit nur eine vorbereitete Vorlage und wird
von `mqtt_mcp_server.py` nicht geladen.

## Twin-Mapping

Dashboard und ROS 2 verwenden denselben Twin-Stand:

| Gelenk | Twin-Eingang |
| --- | --- |
| Basis | `88.9 - S2.pitch`, begrenzt auf `0..100`, visuell `+90..-90` Grad |
| Schulter | negierte Heading-Abweichung von `S2` zu `280.8` Grad |
| Ellbogen | relative Heading-Abweichung `S1` zu `S2` |
| Wrist | negierte relative Roll-Abweichung `S0` zu `S1`, Offset und Stabilisierung |
| Greifer | `f` in `0..100`, geglaettet und auf die visuelle Oeffnung abgebildet |

Der Kollisionssolver ist im aktuellen Dashboard absichtlich deaktiviert, damit
er das direkte Debug-Mapping nicht nachregelt.

Das Mapping des realen Arms in
[`live_i2c_mapping.h`](../firmware/esp32_receiver/live_i2c_mapping.h) ist **nicht
identisch** mit dem Twin: Basisrichtung und Schulterreferenz/-fenster weichen ab;
der Receiver besitzt ausserdem Wrist-Nullung und einen absoluten Roll-Fallback.
Diese Unterschiede koennen Servo- und Visualisierungskoordinaten abbilden und
duerfen nicht durch blindes Kopieren von Konstanten beseitigt werden.

## Start und Funktionscheck

1. Bridge und Mosquitto starten und mit einem nur lesenden Client pruefen, ob
   `robotarm/imu`, `robotarm/status` und `robotarm/kalib` eintreffen.
2. Robotarm-Tab oeffnen. Das Banner muss auf `MQTT: Verbunden` wechseln.
3. Livewerte, Paketzaehler und Notaus-Anzeige gegen einen Roh-Payload abgleichen.
4. Im 3D-Tab jede Achse einzeln bewegen und auf Richtung, Begrenzung und Spruenge
   achten.
5. Fuer den MCP-Pfad zuerst `mqtt_status`, danach `mqtt_read_latest` testen.

Statische Checks aus dem Repository-Root:

```bash
node --check dashboard/web/js/robotarm.js
node --check dashboard/web/js/robotarm_3d.js
python3 -m py_compile dashboard/mcp/mqtt_mcp_server.py
```

## Screenshots

### Live-Daten

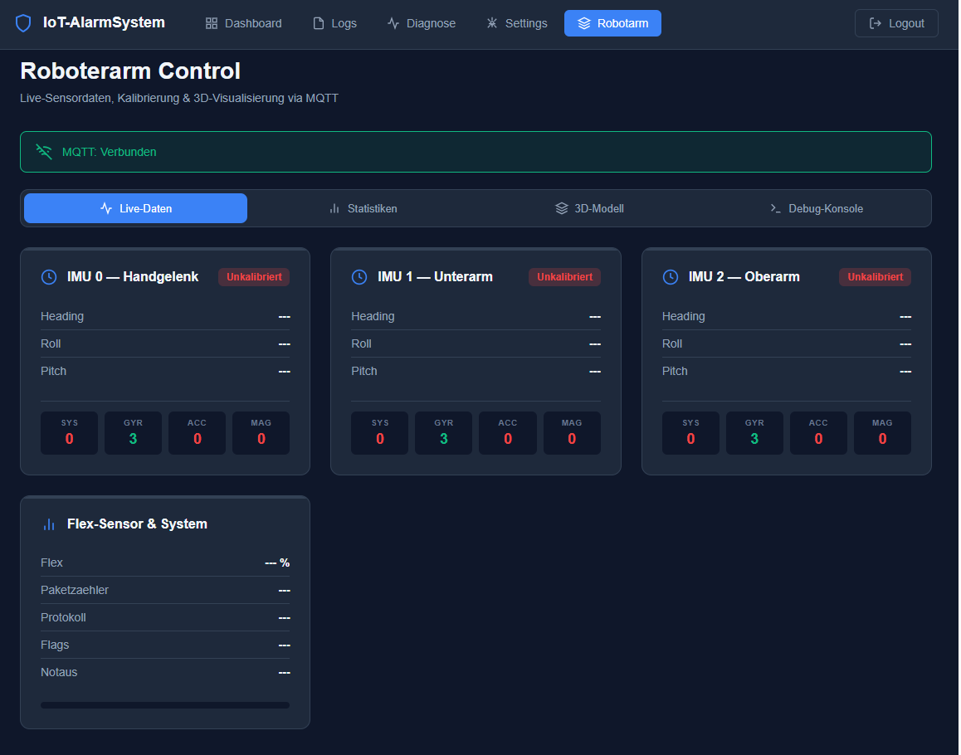
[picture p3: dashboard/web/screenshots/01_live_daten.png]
Live-Daten


### Statistiken

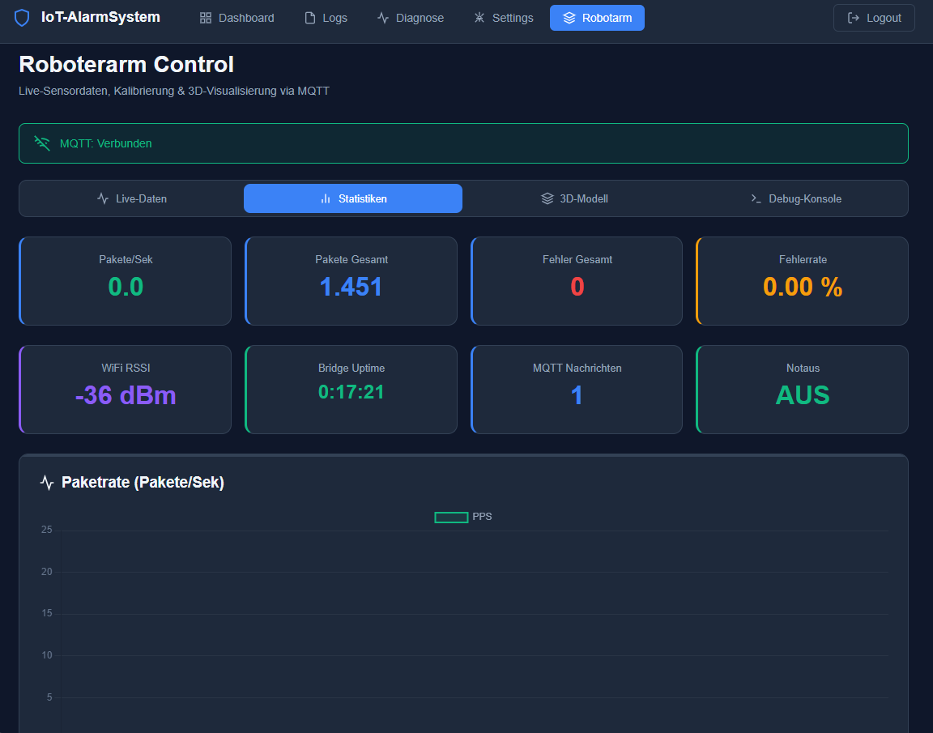
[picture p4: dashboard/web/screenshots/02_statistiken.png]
Statistiken


### 3D-Modell

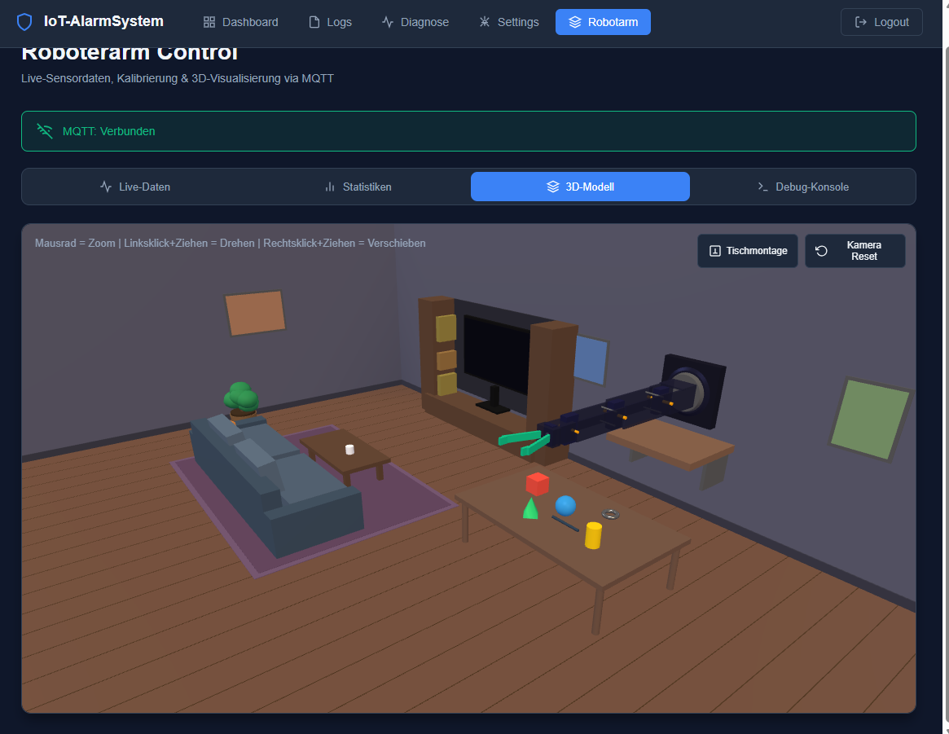
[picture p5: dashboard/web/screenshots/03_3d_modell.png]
3D-Modell


### Debug-Konsole

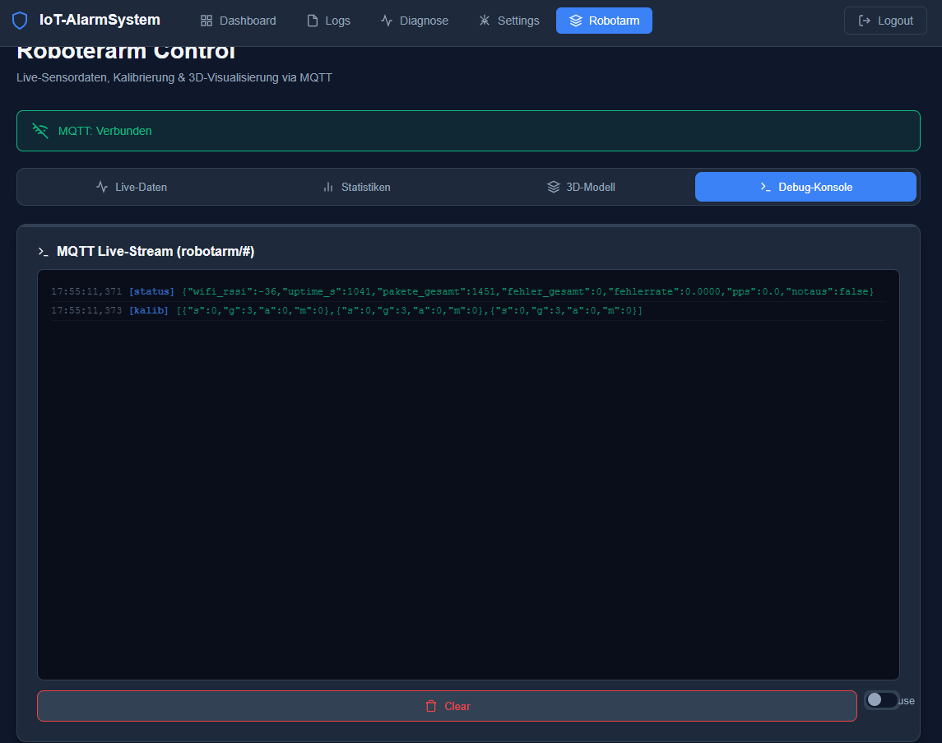
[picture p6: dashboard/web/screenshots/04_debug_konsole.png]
Debug-Konsole


## Grenzen

- Browser, MCP und ROS sind Debugwerkzeuge und geben keine Bewegungsfreigabe.
- Der angezeigte Notaus ist Telemetrie, keine physische Leistungsabschaltung.
- `mqtt_subscribe` uebergibt der `asyncio.Queue` derzeit blockierende
  Argumente, die diese API nicht akzeptiert. Bis zur Korrektur sind
  `mqtt_read_latest` und `mqtt_history` die belastbaren MCP-Lesepfade.
- Das Repository enthaelt nur das Robotarm-Modul, nicht die komplette
  IoT-Control-Center-Hostanwendung oder deren Nginx-/Mosquitto-Laufzeitdateien.
- Zugangsdaten, lokale Hosts und echte MAC-Adressen bleiben ungetrackt.

Weitere Details stehen in
[`docs/PROTOCOL.md`](../docs/PROTOCOL.md),
[`docs/TESTING.md`](../docs/TESTING.md),
[`SECURITY.md`](../SECURITY.md) und im
[`ROS-2-README`](../ros2/README.md).

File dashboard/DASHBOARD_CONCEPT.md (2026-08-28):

# Dashboard-Konzept

Diese kleine Kompatibilitaetsseite bleibt erhalten, weil eine vorhandene
Konfigurationsvorlage darauf verweist. Betrieb, Topics, Twin-Mapping und
bekannte Grenzen stehen im [`dashboard/README.md`](README.md). Der Debugpfad
ist separat vom Bewegungsweg und bleibt ein aktiver Teil des Repositories.

## OTA-Sicherheitskonzept

`mcp/ota_config.template.py` ist eine Vorlage; der aktuelle
`mqtt_mcp_server.py` laedt sie nicht. Eine spaetere OTA-Aktivierung waere ein
sicherheitskritischer Schreibpfad und braucht vor jeder Implementierung:

- ein eigenes, starkes OTA-Geheimnis statt Platzhaltern oder gemeinsam
  genutzten WiFi-/MQTT-Passwoertern;
- lokale, gitignorierte Konfiguration mit restriktiven Dateirechten;
- Netzwerksegmentierung und eine explizite Ziel- und Firmwarepruefung;
- einen eng begrenzten Broker-/Dienstaccount statt Schreibrecht auf
  `robotarm/#`;
- nachvollziehbares Logging sowie eine getestete Recovery-Moeglichkeit;
- eine physisch sichere Armkonfiguration mit getrenntem Servostrom waehrend
  Flash und Neustart.

Der MCP-Server ist wegen seines vorhandenen `mqtt_publish`-Werkzeugs nicht
intrinsisch read-only. Die mitgelieferte Broker-ACL muss Schreibversuche des
Reader-Kontos wirksam blockieren. Weitere Regeln stehen in
[`SECURITY.md`](../SECURITY.md).

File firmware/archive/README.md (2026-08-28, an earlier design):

# Firmware-Archiv

Dieser Ordner enthaelt historische oder einmalige Diagnose-Sketches. Sie bleiben
als nachvollziehbare Entwicklungsstaende erhalten, gehoeren aber nicht zum
aktiven Build- oder Flashpfad.

## Struktur

- `espnow/`: abgeloeste ESP-NOW-Sender und -Receiver der Versionen 1 und 2
- `uart/`: abgeloeste UART-Kette zwischen ESP32-Receiver und Arduino; Format in
  [`firmware/UART_FRAME_V1.md`](../UART_FRAME_V1.md)
- `bringup/`: einmalige Sensor-, Mux- und Eingabetests fuer den Hardware-Bring-up

Die aktive Firmware liegt weiterhin direkt unter `firmware/esp32_controller/`,
`firmware/esp32_receiver/`, `firmware/esp32_bridge/` und
`firmware/arduino_arm/`. Archiv-Sketches duerfen nicht versehentlich als
aktueller Referenzstand gebaut oder geflasht werden.

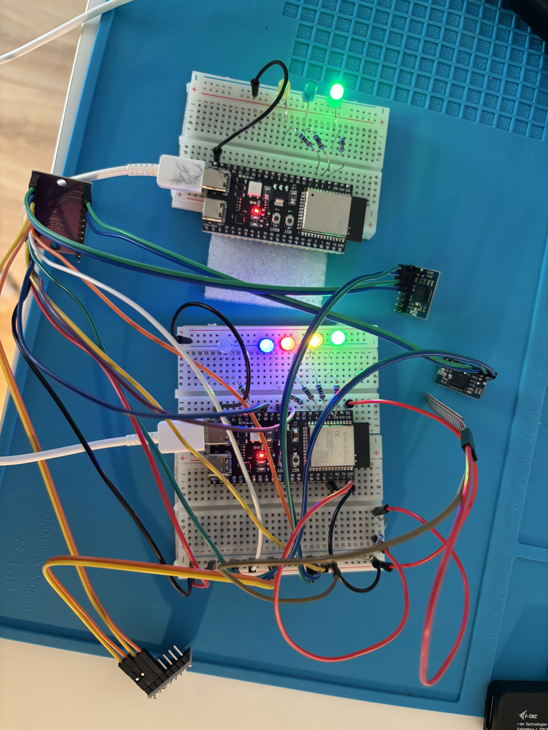
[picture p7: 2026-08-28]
docs/photos/2026-03-26_bench_breadboards_detail.jpg

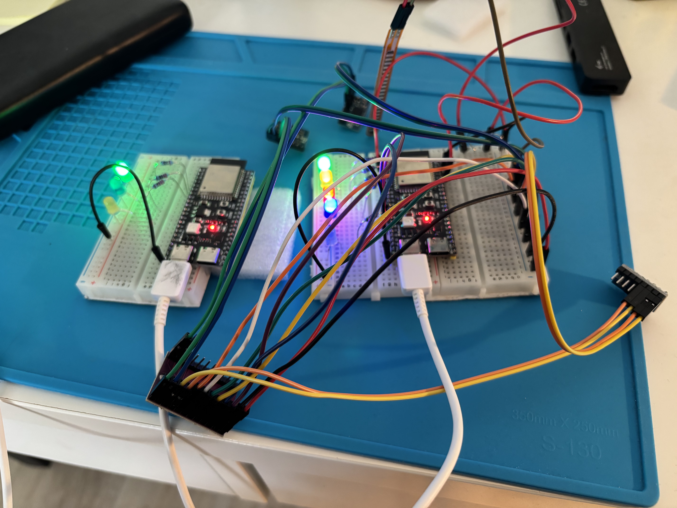
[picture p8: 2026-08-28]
docs/photos/2026-03-26_bench_breadboards_uebersicht.jpg

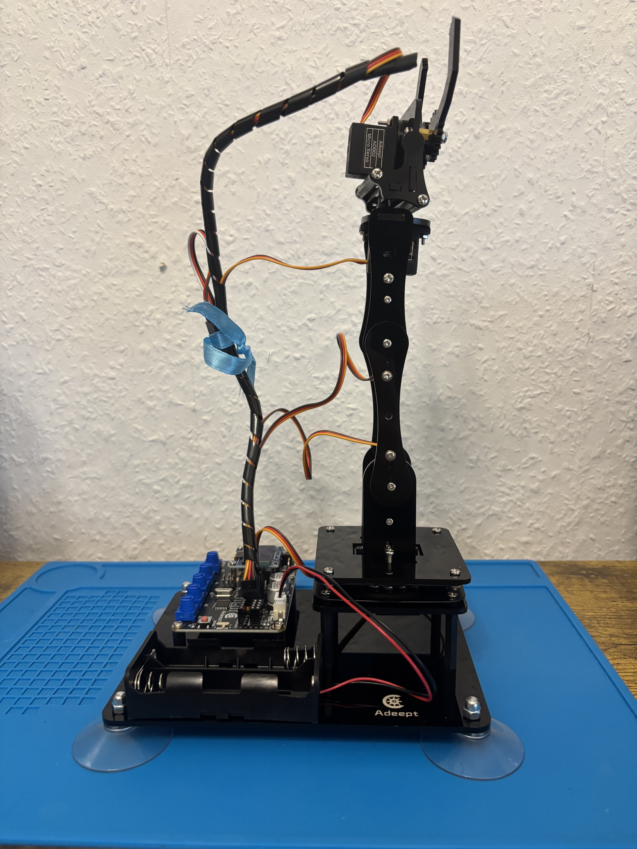
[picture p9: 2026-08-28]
docs/photos/2026-03-24_roboterarm_seitenansicht.jpg

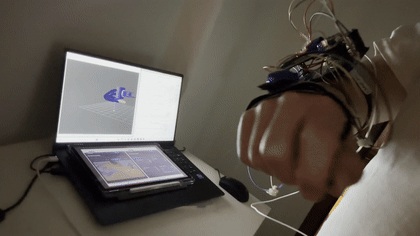
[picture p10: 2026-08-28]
documentation/snapshot/docs/photos/readme/20260423_213652000-ios.gif

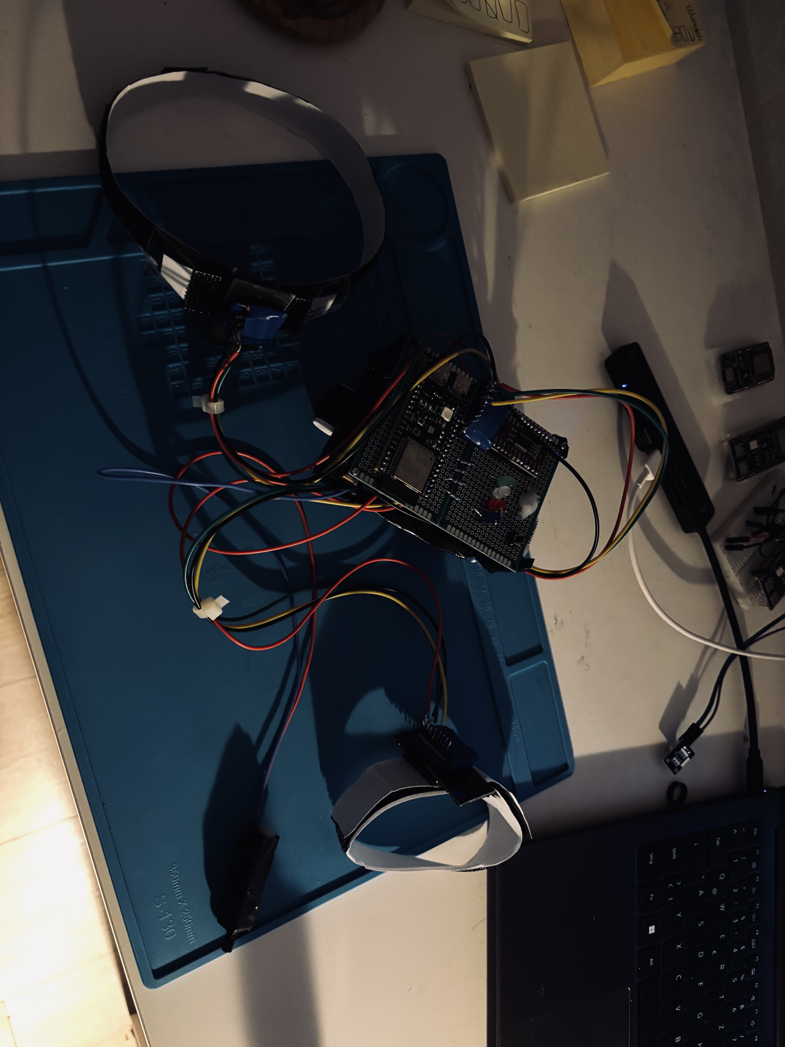
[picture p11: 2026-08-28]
docs/photos/2026-05-10_robotarm_finaler_prototyp.jpg

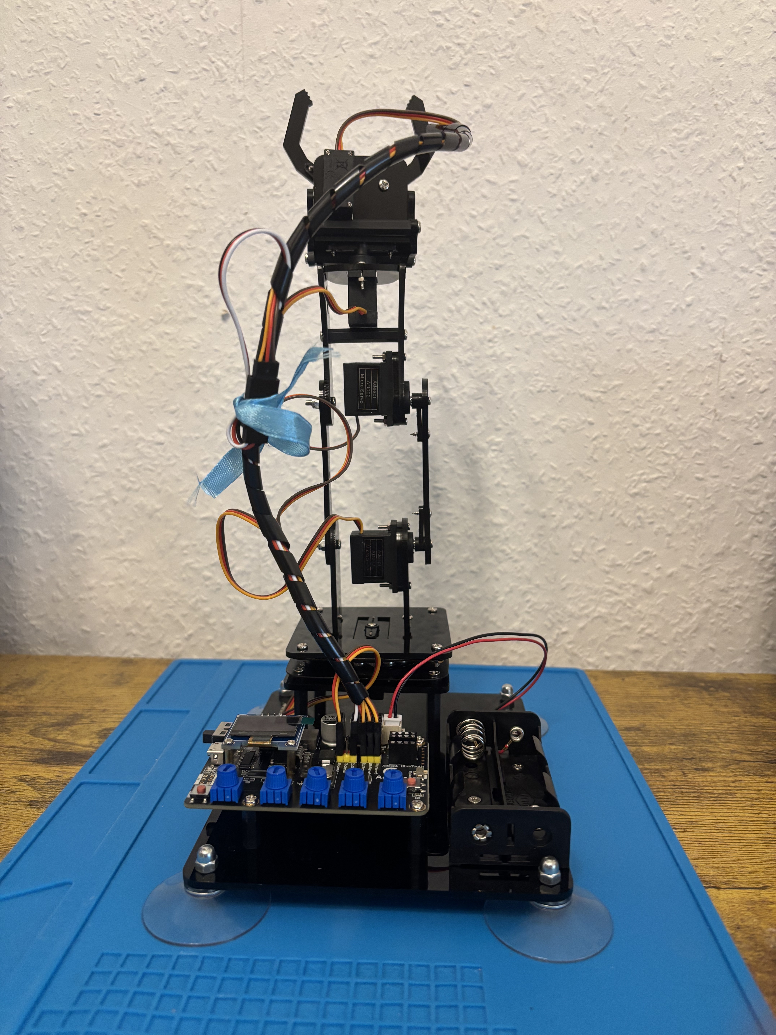
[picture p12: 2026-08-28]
docs/photos/2026-03-24_roboterarm_rueckansicht.jpg

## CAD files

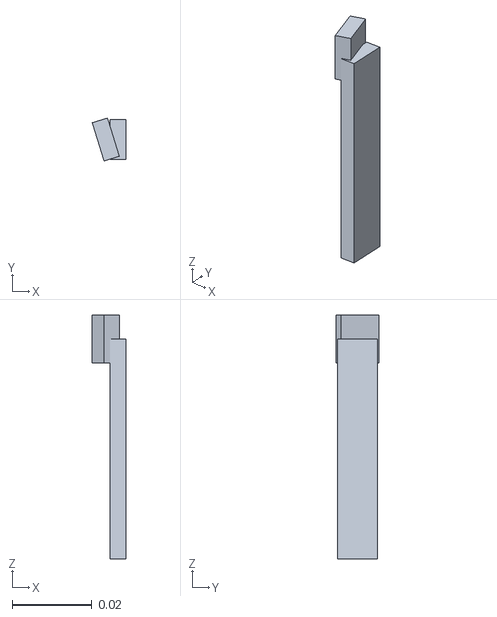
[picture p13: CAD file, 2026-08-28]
ros2/src/robotarm_description/meshes/gripper_right.stl
0.00839 x 0.0107 x 0.061

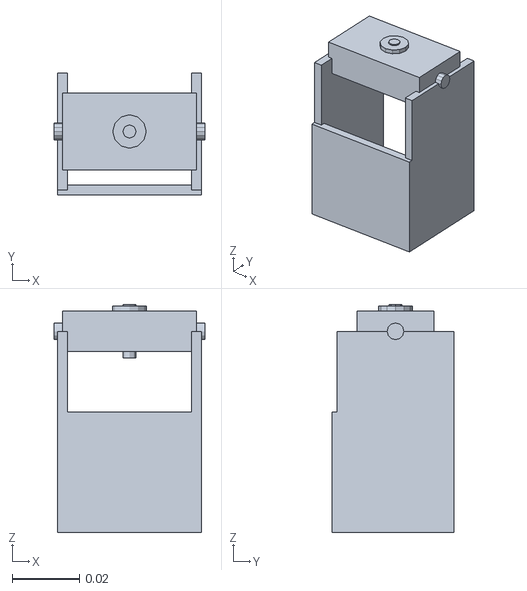
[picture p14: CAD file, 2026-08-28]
ros2/src/robotarm_description/meshes/shoulder_bracket.stl
0.045 x 0.0365 x 0.068

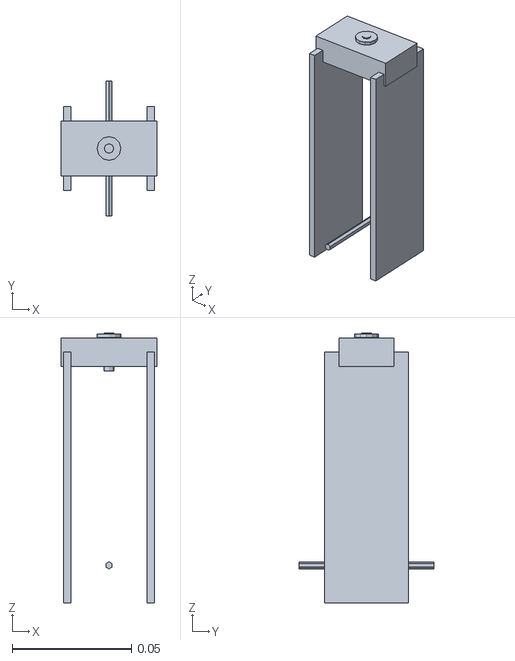
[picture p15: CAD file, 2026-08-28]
ros2/src/robotarm_description/meshes/upper_arm.stl
0.04 x 0.0565 x 0.113

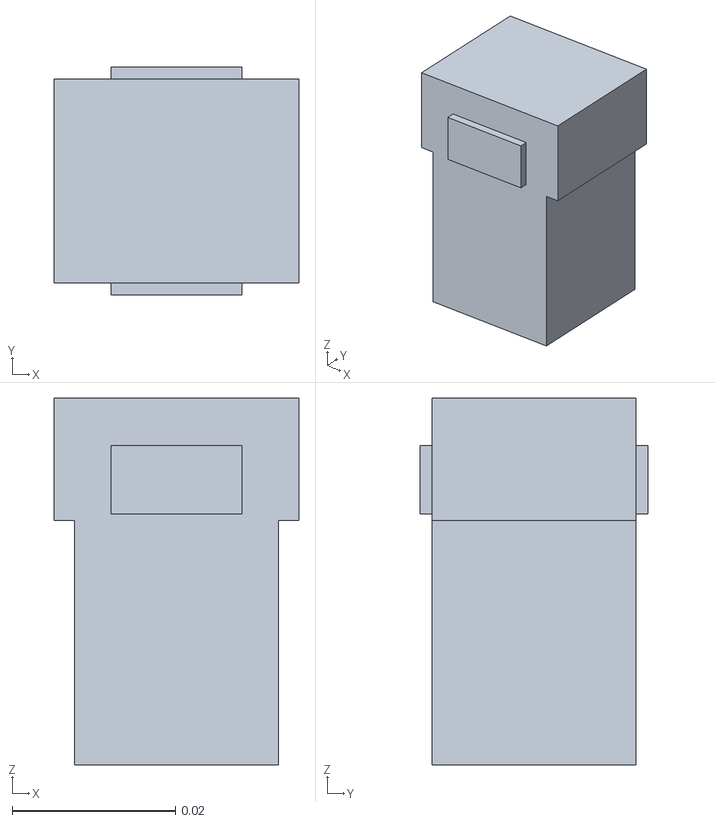
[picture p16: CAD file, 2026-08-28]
ros2/src/robotarm_description/meshes/wrist.stl
0.03 x 0.028 x 0.045

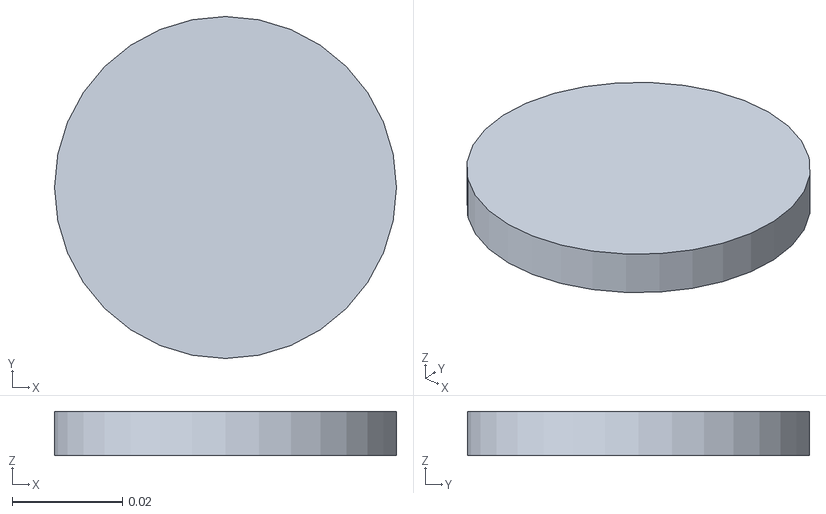
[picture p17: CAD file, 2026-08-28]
ros2/src/robotarm_description/meshes/turntable.stl
0.062 x 0.062 x 0.008

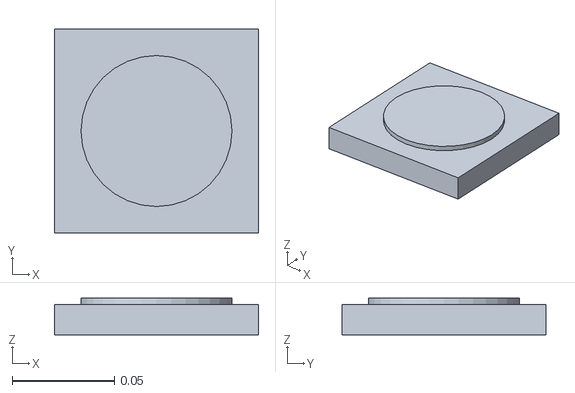
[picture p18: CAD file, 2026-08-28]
ros2/src/robotarm_description/meshes/base_link.stl
0.1 x 0.1 x 0.018

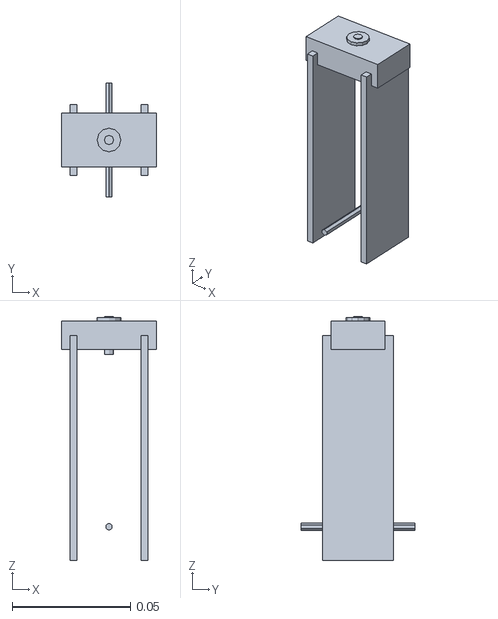
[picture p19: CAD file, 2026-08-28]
ros2/src/robotarm_description/meshes/forearm.stl
0.04 x 0.048 x 0.103

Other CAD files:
ros2/src/robotarm_description/meshes/gripper_left.stl

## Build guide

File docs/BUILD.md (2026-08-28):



<div align="center">




</div>

---

# Build und Flashen

Diese Anleitung beschreibt die aktiven Firmwareziele. Ein erfolgreicher
`Compile-Check` beweist nur, dass der Quellstand mit der genannten Toolchain
uebersetzt werden kann; er ist keine neue Hardware-, Safety- oder Flash-Freigabe.

## Ziele

| Komponente | Aktiver Sketch | Ziel |
| --- | --- | --- |
| Controller | [`firmware/esp32_controller/esp32_controller.ino`](../firmware/esp32_controller/esp32_controller.ino) | ESP32-S3-WROOM-1-N16R8 |
| Receiver | [`firmware/esp32_receiver/esp32_receiver.ino`](../firmware/esp32_receiver/esp32_receiver.ino) | ESP32-S3-WROOM-1-N16R8 |
| Debug-Bridge | [`firmware/esp32_bridge/esp32_bridge.ino`](../firmware/esp32_bridge/esp32_bridge.ino) | ESP32-S3-WROOM-1-N16R8 |
| Servoebene | [`firmware/arduino_arm/arduino_arm.ino`](../firmware/arduino_arm/arduino_arm.ino) | Arduino UNO / ATmega328P |

Dateien unter [`firmware/archive/`](../firmware/archive/) sind historische Referenzen und keine aktiven Build- oder Flashziele.

Der primaere Projektweg bleibt ein Arduino-Sketch ueber `Arduino IDE` oder
`Arduino CLI`. Die vorhandenen `PlatformIO`-Dateien dienen als Fallback und
Build-Gegencheck; Upload-Anleitungen muessen klar nennen, welcher Weg verwendet
wurde.

## ESP32-Boarddefinition: bekannte Reproduzierbarkeitsluecke

Der reale Uploadpfad verwendet das lokale Custom-FQBN:

```text
esp32:esp32:robotic_arm_s3n16r8
```

Die zugehoerige `boards.local.txt` liegt derzeit nur in der lokalen Arduino-Installation und ist nicht Bestandteil des Repositories. Ein frischer Clone kann dieses FQBN daher nicht allein aus dem Repo rekonstruieren. Vor einem Upload muss

```powershell
arduino-cli board details -b "esp32:esp32:robotic_arm_s3n16r8"
```

die lokale Definition erfolgreich finden. Fehlt sie, ist der Hardware-Upload blockiert, bis die bestaetigte Boarddefinition separat bereitgestellt wurde.

Fuer den reinen Compile-Check vom 2026-08-28 wurde ersatzweise dieses explizit konfigurierte generische FQBN verwendet:

```text
esp32:esp32:esp32s3:FlashSize=16M,PSRAM=opi,CDCOnBoot=cdc
```

Das ist ein Syntax-/Buildnachweis und keine Freigabe, das generische Board auf die reale Hardware zu flashen. Die vorhandenen `platformio.ini`-Dateien fuer [Controller](../firmware/esp32_controller/platformio.ini) und [Receiver](../firmware/esp32_receiver/platformio.ini) bleiben ebenfalls nur Fallback und Gegencheck.

## Lokale Konfiguration

Echte MAC-Adressen, Netzwerkdaten und Passwoerter duerfen nicht committed werden. Vor einem lokalen Build die benoetigten Vorlagen kopieren und nur die gitignorierte Kopie bearbeiten:

| Komponente | Vorlage | Lokale Datei |
| --- | --- | --- |
| Controller | [`peer_config.template.h`](../firmware/esp32_controller/peer_config.template.h) | `peer_config.local.h` |
| Bridge | [`peer_config.template.h`](../firmware/esp32_bridge/peer_config.template.h) | `peer_config.local.h` |
| Bridge | [`wifi_config.template.h`](../firmware/esp32_bridge/wifi_config.template.h) | `wifi_config.local.h` |

Im Controller-Template ist `BRIDGE_AKTIV=0`. Fuer den aktiven Debug-/Twin-Pfad muss diese Option ausschliesslich in der lokalen Kopie bewusst auf `1` gesetzt und die Bridge als zweiter Peer eingetragen werden. Platzhalterdateien reichen fuer einen Compile-Check, duerfen aber nicht als betriebsfertige Peer-Konfiguration geflasht werden.

## Nachgewiesener Buildstand vom 2026-08-28

Der Check lief mit `arduino-cli 1.5.1`, ESP32-Core `3.3.5` und AVR-Core `1.8.8`. `arduino-cli 1.5.1` und AVR-Core `1.8.8` waren am Auditdatum die aktuellen stabilen Releases; `arduino-cli 1.5.2-rc.1` war nur ein Pre-Release. Die Libraries wurden aus dem frisch aktualisierten Arduino-Index in einem isolierten temporaeren Verzeichnis bereitgestellt:

| Library | Version | Verwendet von |
| --- | --- | --- |
| Adafruit BNO055 | 1.6.4 | Controller |
| Adafruit Unified Sensor | 1.1.15 | Controller |
| Adafruit BusIO | 1.17.4 | transitive Adafruit-Abhaengigkeit |
| Adafruit NeoPixel | 1.15.5 | Controller und Receiver |
| Servo | 1.3.0 | Arduino-Servoebene |

Der Arduino-Index und das offizielle Espressif-Release meldeten fuer den
ESP32-Core bereits `3.3.11` als aktuelle stabile Version. Sie wurde nur
auditiert, nicht fuer diese Hardware gebaut oder freigegeben; ein Update ist
deshalb keine automatische Upgrade-Empfehlung.

Ergebnis des frischen Compile-Checks:

| Ziel | Flash | RAM | Ergebnis |
| --- | ---: | ---: | --- |
| Controller | 930311 B | 45544 B | erfolgreich |
| Receiver, Repo-Default | 902395 B | 45104 B | erfolgreich |
| Receiver, Live-I2C alle Achsen | 904751 B | 45136 B | erfolgreich |
| Arduino UNO | 4280 B | 282 B | erfolgreich |

Die aktive Debug-Bridge wurde in diesem Audit nicht frisch kompiliert. Aus dem Quellcode folgen zusaetzlich `PubSubClient`, Adafruit NeoPixel sowie die mit dem ESP32-Core gelieferten WiFi-, ESP-NOW- und ArduinoOTA-Komponenten; daraus wird hier kein aktueller Bridge-Builderfolg abgeleitet.

## Reproduzierbare Compile-Checks

Die folgenden Befehle setzen voraus, dass die oben genannten Libraries installiert oder ueber `--libraries` eingebunden und die erforderlichen lokalen Header vorhanden sind.

```powershell
arduino-cli compile --fqbn "esp32:esp32:esp32s3:FlashSize=16M,PSRAM=opi,CDCOnBoot=cdc" firmware/esp32_controller
arduino-cli compile --fqbn "esp32:esp32:esp32s3:FlashSize=16M,PSRAM=opi,CDCOnBoot=cdc" firmware/esp32_receiver
arduino-cli compile --fqbn "arduino:avr:uno" firmware/arduino_arm
```

Der committed Receiver-Default ist der Test-Sweep. Der nachgewiesene Live-All-Axes-Build veraendert keine Quelldatei und nutzt exakt diese Build-Flags:

```powershell
arduino-cli compile --fqbn "esp32:esp32:esp32s3:FlashSize=16M,PSRAM=opi,CDCOnBoot=cdc" --build-property "compiler.cpp.extra_flags=-DRECEIVER_MODE_TEST_SWEEP=0 -DRECEIVER_MODE_LIVE_I2C=1 -DRECEIVER_LIVE_ENABLE_BASIS=1 -DRECEIVER_LIVE_ENABLE_SHOULDER=1 -DRECEIVER_LIVE_ENABLE_ELBOW=1 -DRECEIVER_LIVE_ENABLE_WRIST=1 -DRECEIVER_LIVE_ENABLE_GRIPPER=1" firmware/esp32_receiver
```

`RECEIVER_I2C_SEND_ENABLED` bleibt dabei auf seinem Quellcode-Default `1`. Fuer einen reinen Mapping-Dry-Run kann es als zusaetzliches Build-Flag auf `0` gesetzt werden; dieser Dry-Run ist nicht Teil des oben protokollierten Checks.

## Vor einem realen Upload

1. Custom-FQBN und aktuellen Port lokal pruefen.
2. Lokale Peer-/Netzwerkkonfiguration auf das richtige Geraet begrenzen.
3. Receiver-Modus und alle Achsenfreigaben bewusst kontrollieren.
4. Stromversorgung, I2C-Pegel und mechanische Freigabe nach [`HARDWARE.md`](HARDWARE.md#deutsch) und [`SAFETY.md`](../SAFETY.md#deutsch) pruefen.
5. Erst danach mit dem Custom-FQBN flashen und den Testplan aus [`TESTING.md`](TESTING.md#deutsch) abarbeiten.

<div align="center">



</div>

---

# Build and Flashing

This guide describes the active firmware targets. A successful `compile check`
only proves that the source state can be translated with the stated toolchain;
it is not a new hardware, safety, or flashing approval.

## Targets

| Component | Active sketch | Target |
| --- | --- | --- |
| Controller | [`firmware/esp32_controller/esp32_controller.ino`](../firmware/esp32_controller/esp32_controller.ino) | ESP32-S3-WROOM-1-N16R8 |
| Receiver | [`firmware/esp32_receiver/esp32_receiver.ino`](../firmware/esp32_receiver/esp32_receiver.ino) | ESP32-S3-WROOM-1-N16R8 |
| Debug bridge | [`firmware/esp32_bridge/esp32_bridge.ino`](../firmware/esp32_bridge/esp32_bridge.ino) | ESP32-S3-WROOM-1-N16R8 |
| Servo layer | [`firmware/arduino_arm/arduino_arm.ino`](../firmware/arduino_arm/arduino_arm.ino) | Arduino UNO / ATmega328P |

Files under [`firmware/archive/`](../firmware/archive/) are historical references and are not active build or flash targets.

The primary project workflow remains an Arduino sketch through `Arduino IDE` or
`Arduino CLI`. The existing `PlatformIO` files serve as a fallback and build
cross-check; upload instructions must state clearly which route was used.

## ESP32 Board Definition: Known Reproducibility Gap

The real upload path uses the local custom FQBN:

```text
esp32:esp32:robotic_arm_s3n16r8
```

The corresponding `boards.local.txt` currently exists only in the local Arduino installation and is not part of the repository. A fresh clone therefore cannot reconstruct this FQBN from the repository alone. Before an upload,

```powershell
arduino-cli board details -b "esp32:esp32:robotic_arm_s3n16r8"
```

must find the local definition successfully. If it is missing, hardware upload remains blocked until the confirmed board definition has been supplied separately.

For the compile-only check on 2026-08-28, the following explicitly configured generic FQBN was used instead:

```text
esp32:esp32:esp32s3:FlashSize=16M,PSRAM=opi,CDCOnBoot=cdc
```

This is syntax/build evidence and not approval to flash the generic board definition onto the real hardware. The existing `platformio.ini` files for the [controller](../firmware/esp32_controller/platformio.ini) and [receiver](../firmware/esp32_receiver/platformio.ini) likewise remain fallback and cross-check paths only.

## Local Configuration

Real MAC addresses, network data, and passwords must not be committed. Before a local build, copy the required templates and edit only the gitignored copy:

| Component | Template | Local file |
| --- | --- | --- |
| Controller | [`peer_config.template.h`](../firmware/esp32_controller/peer_config.template.h) | `peer_config.local.h` |
| Bridge | [`peer_config.template.h`](../firmware/esp32_bridge/peer_config.template.h) | `peer_config.local.h` |
| Bridge | [`wifi_config.template.h`](../firmware/esp32_bridge/wifi_config.template.h) | `wifi_config.local.h` |

The controller template sets `BRIDGE_AKTIV=0`. For the active debug/digital-twin path, this option must be deliberately changed to `1` only in the local copy and the bridge must be entered as the second peer. Placeholder files are sufficient for a compile check, but must not be flashed as an operational peer configuration.

## Verified Build State on 2026-08-28

The check used `arduino-cli 1.5.1`, ESP32 core `3.3.5`, and AVR core `1.8.8`. `arduino-cli 1.5.1` and AVR core `1.8.8` were the current stable releases on the audit date; `arduino-cli 1.5.2-rc.1` was only a pre-release. The libraries were provided from the freshly updated Arduino index in an isolated temporary directory:

| Library | Version | Used by |
| --- | --- | --- |
| Adafruit BNO055 | 1.6.4 | Controller |
| Adafruit Unified Sensor | 1.1.15 | Controller |
| Adafruit BusIO | 1.17.4 | transitive Adafruit dependency |
| Adafruit NeoPixel | 1.15.5 | Controller and receiver |
| Servo | 1.3.0 | Arduino servo layer |

The Arduino index and the official Espressif release already identified
ESP32 core `3.3.11` as the current stable version. It was audited only, not
built or approved for this hardware; an update is therefore not an automatic
upgrade recommendation.

Result of the fresh compile check:

| Target | Flash | RAM | Result |
| --- | ---: | ---: | --- |
| Controller | 930311 B | 45544 B | successful |
| Receiver, repository default | 902395 B | 45104 B | successful |
| Receiver, live I2C on all axes | 904751 B | 45136 B | successful |
| Arduino UNO | 4280 B | 282 B | successful |

The active debug bridge was not freshly compiled in this audit. Its source additionally requires `PubSubClient`, Adafruit NeoPixel, and the WiFi, ESP-NOW, and ArduinoOTA components supplied with the ESP32 core; no current bridge build success is inferred from that fact.

## Reproducible Compile Checks

The following commands assume that the libraries listed above are installed or included through `--libraries` and that the required local headers exist.

```powershell
arduino-cli compile --fqbn "esp32:esp32:esp32s3:FlashSize=16M,PSRAM=opi,CDCOnBoot=cdc" firmware/esp32_controller
arduino-cli compile --fqbn "esp32:esp32:esp32s3:FlashSize=16M,PSRAM=opi,CDCOnBoot=cdc" firmware/esp32_receiver
arduino-cli compile --fqbn "arduino:avr:uno" firmware/arduino_arm
```

The committed receiver default is the test sweep. The verified live-all-axes build does not modify any source file and uses exactly these build flags:

```powershell
arduino-cli compile --fqbn "esp32:esp32:esp32s3:FlashSize=16M,PSRAM=opi,CDCOnBoot=cdc" --build-property "compiler.cpp.extra_flags=-DRECEIVER_MODE_TEST_SWEEP=0 -DRECEIVER_MODE_LIVE_I2C=1 -DRECEIVER_LIVE_ENABLE_BASIS=1 -DRECEIVER_LIVE_ENABLE_SHOULDER=1 -DRECEIVER_LIVE_ENABLE_ELBOW=1 -DRECEIVER_LIVE_ENABLE_WRIST=1 -DRECEIVER_LIVE_ENABLE_GRIPPER=1" firmware/esp32_receiver
```

`RECEIVER_I2C_SEND_ENABLED` remains at its source-code default of `1`. For a mapping-only dry run, it can be set to `0` through an additional build flag; that dry run is not part of the check recorded above.

## Before a Real Upload

1. Check the custom FQBN and current port locally.
2. Limit the local peer/network configuration to the correct device.
3. Deliberately verify the receiver mode and every axis enable flag.
4. Check the power supply, I2C levels, and mechanical approval against [`HARDWARE.md`](HARDWARE.md#english) and [`SAFETY.md`](../SAFETY.md#english).
5. Only then flash with the custom FQBN and follow the test plan in [`TESTING.md`](TESTING.md#english).

<div align="center">



</div>

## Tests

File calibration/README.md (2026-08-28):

# Kalibrierung und Realarm-Mapping

Diese Datei ist die kompakte Referenz fuer die aktive Sensorzuordnung,
Kalibrierung, Referenzpose, Greiferanker, Servogrenzen und die tatsaechliche
Realarm-Abbildung. Fuer die reale Servoausgabe ist
[`live_i2c_mapping.h`](../firmware/esp32_receiver/live_i2c_mapping.h) die
Implementierungsquelle; Dashboard und ROS sind separate Twin-Abbildungen.

Historische Flex-Sensor-, Breadboard- und 90-Grad-Montagestaende sind keine
aktiven Betriebsparameter.

## Sensorzuordnung

| Index | PCA9548A-Kanal | Segment | BNO055-Adresse |
| --- | ---: | --- | --- |
| `S0` | `0` | Hand/Wrist | `0x29` |
| `S1` | `1` | Unterarm | `0x29` |
| `S2` | `2` | Oberarm | `0x29` |

Der Multiplexer hat die Adresse `0x70`; Controller-SDA/SCL liegen auf
`GPIO8/GPIO9`. Montageposition und Achsausrichtung muessen bei jedem erneuten
Anlegen reproduziert werden. Eine verdrehte IMU macht gespeicherte Offsets oder
Referenzwerte nicht automatisch wieder passend.

## BNO055-Kalibrierung

Der Controller speichert fuer jeden Sensor eigene Offsets im NVS-Namespace
`imu_kalib` und laedt sie beim Boot. Automatisch gespeichert wird erst, wenn
`Gyro`, `Accel` und `Mag` jeweils mindestens Status `3` fuer drei aufeinander
folgende Pruefungen erreichen. `Sys` ist kein Speicherkriterium.

Serielle Befehle bei `115200 Baud`:

| Befehl | Wirkung |
| --- | --- |
| `CAL0`, `CAL1`, `CAL2` | nur den entsprechenden Sensor kalibrieren; bestehende Offsets bleiben bis zu einer erfolgreichen neuen Speicherung erhalten |
| `STOP` | laufende Einzelkalibrierung abbrechen |
| `CALSTAT` | NVS-, effektiven und aktuellen Live-Status aller Sensoren anzeigen |
| `RECAL` | alle drei gespeicherten Offsetsaetze loeschen |

Vorgehen:

1. Sensor fest in seiner realen Montageposition befestigen und Servoenergie
   getrennt lassen.
2. `CALn` fuer genau einen Sensor starten.
3. Fuer Gyro ruhig halten, fuer Accel mehrere feste Lagen durchlaufen und fuer
   Mag langsam um alle Achsen bewegen, fern von Servo-, Akku-, Metall- und
   USB-Stoerquellen.
4. Speicherungsmeldung abwarten und danach mit `CALSTAT` pruefen.
5. Referenzpose erneut aufnehmen, wenn Montage oder Achsausrichtung geaendert
   wurde.

Die Hintergrunddiagnose ist im normalen Livepfad bewusst aus, weil zusaetzliche
BNO055-Abfragen Paketpausen erzeugen koennen.

## Wearable-Referenzpose

Arbeitsreferenz vom 2026-04-23: Arm seitlich am Koerper entspannt
herunterhaengend, Schulter locker, Unterarm nicht aktiv gebeugt, Hand neutral.

| Sensor | Heading | Roll | Pitch |
| --- | ---: | ---: | ---: |
| `S0` Hand/Wrist | 255.0 Grad | -5.5 Grad | 65.8 Grad |
| `S1` Unterarm | 260.3 Grad | -10.7 Grad | 86.0 Grad |
| `S2` Oberarm | 280.8 Grad | 13.2 Grad | 88.9 Grad |

Diese Messung ist eine reproduzierbare Arbeitsreferenz, keine anatomische
Weltkoordinate. Der Realarm-Code verwendet sie nicht fuer jede Achse als
Mittelpunkt: insbesondere besitzt die aktive Schulterabbildung eine separate
Heading-Referenz von `240 Grad`.

## Greifer-Potentiometer

Aktiver Aufbau: aeusserer Poti-Pin an `3.3 V`, Wischer an `GPIO1`, vorhandener
10-kOhm-Pull-down von ADC nach GND. Die Firmware mittelt 16 ADC-Messungen,
filtert mit `alpha=0.18` und verwendet eine Rohwert-Totzone von 2 Counts.

| Zustand | ADC-Anker | Protokollwert `f` |
| --- | ---: | ---: |
| offen / Ruhelage | 1935 | 0 % |
| geschlossen | 3020 | 100 % |

Zwischenwerte werden linear abgebildet und auf `0..100 %` begrenzt. Das Feld
heisst aus Kompatibilitaetsgruenden weiterhin `flex_prozent`, obwohl der aktive
Sensor ein Potentiometer ist. Werte unter 200 gelten als unplausibel; das offene
Ende des 2-Draht-Potis darf bis zum ADC-Maximum 4095 reichen.

## Aktive Realarm-Abbildung

Der Receiver berechnet zunaechst Zielbytes `0..255`; der Arduino mappt diese auf
die empirischen Servogrenzen. Die folgende Tabelle beschreibt den aktiven Code,
nicht eine ideale Kinematik.

| Achse | Realarm-Eingang und Begrenzung | Byte-/Servoausgabe |
| --- | --- | --- |
| Basis | `clamp(88.9 - S2.pitch, 0, 100)` | linear `0..255` -> 12..139 Grad |
| Schulter | normierte Differenz `S2.heading - 240`, begrenzt auf `-60..60` | linear `0..255` -> 35..142 Grad |
| Ellbogen | Referenzrelation `S1.heading - S2.heading = -20.5`; `Referenz - aktuelle Relation`, begrenzt auf `0..45` | linear `0..255` -> 80..175 Grad |
| Handgelenk | negative relative Roll-Differenz `S0` zu `S1`, Offset `+10.2 Grad`, sicher begrenzt auf `-75..75 Grad` | Kodierfenster `-90..90` -> 5..177 Grad |
| Greifer | `f`, begrenzt auf `0..100 %` | linear `0..255` -> 32..126 Grad |

Besonderheiten des Handgelenks:

- Wenn der absolute Hand-Roll groesser als `35 Grad` ist und die relative
  Roll-Differenz kleiner als `25 Grad`, verwendet der Realarm einen
  Absolut-Roll-Fallback.
- Spruenge groesser als `90 Grad` werden gehalten.
- In der Fold-Zone ab `abs(S0.pitch) >= 145 Grad` greift eine Latch-/Hold-Logik.
- `WRISTZERO` setzt den Mittelpunkt beim naechsten gueltigen Paket neu;
  `WRISTSTAT` zeigt Rohwert, Ziel und Offset.

Bei Nullframes haelt die Schulter ihren letzten Wert; der Ellbogen haelt nach
der ersten Initialisierung ebenfalls den letzten Wert, wenn `S1` oder `S2`
komplett Null liefern. Zusaetzlich haelt bereits der Controller den letzten
gueltigen IMU-Wert bei einzelnen Nullframes.

## Achsenfreigabe und Glattung

Im committed Receiver-Default ist Live-I2C aus und der Test-Sweep an. Im
Live-Build wird jede nicht explizit freigegebene Achse auf Byte `128` gefuehrt.
Der Receiver begrenzt die Aenderung pro 20-ms-Frame auf:

- Basis und Schulter: 2 Byte
- Ellbogen und Handgelenk: 8 Byte
- Greifer: 12 Byte

Der Arduino begrenzt danach jede physische Achse erneut auf 3 Grad pro 20 ms.
Timeout, Software-Stop und Betriebsfreigabe sind in
[`SAFETY.md`](../SAFETY.md) beschrieben.

## Servogrenzen und Rueckfallwerte

| Gelenk | Pin | Min | Max | aktiver Mittel-/Rueckfallwert |
| --- | ---: | ---: | ---: | ---: |
| Basis | `D9` | 12 Grad | 139 Grad | 75 Grad |
| Schulter | `D11` | 35 Grad | 142 Grad | 88 Grad |
| Ellbogen | `D3` | 80 Grad | 175 Grad | 127 Grad |
| Handgelenk | `D5` | 5 Grad | 177 Grad | 91 Grad |
| Greifer | `D6` | 32 Grad | 126 Grad | 79 Grad |

Die Werte sind am Prototyp empirisch ermittelt. `90 Grad` bleibt nur als
historische Montage-/Erstmessposition relevant und ist nicht die aktive
Rueckfallpose.

## Abgrenzung zum Digital Twin

Dashboard und ROS visualisieren denselben Sensorstrom, sind aber aktuell nicht
bitgenau identisch mit dem Realarm-Mapping:

- Der Twin bezieht die Schulter auf `S2.heading = 280.8 Grad`, invertiert die
  Differenz und nutzt `0..60`; der Realarm bezieht sie auf `240 Grad` und nutzt
  `-60..60`.
- Die Basis verwendet denselben Pitch-Eingang, aber eine andere
  Ausgaberichtung/-skala.
- Der Realarm besitzt den beschriebenen Wrist-Absolut-Roll-Fallback; die
  Twin-Abbildung bildet diesen Sonderfall nicht identisch ab.

Deshalb ist der Twin ein Debug- und Beobachtungspfad, keine kalibrierte
Istpositionsanzeige des Servos. Aenderungen an Twin oder Realarm duerfen nicht
als automatisch synchron angenommen werden.

## Implementierungsquellen

- [Controller-Sensorik und NVS-Kalibrierung](../firmware/esp32_controller/esp32_controller.ino)
- [Realarm-Mapping](../firmware/esp32_receiver/live_i2c_mapping.h)
- [Receiver-Freigaben und Byte-Slew](../firmware/esp32_receiver/esp32_receiver.ino)
- [Arduino-Limits und Rueckfallwerte](../firmware/arduino_arm/arduino_arm.ino)
- [Dashboard-Mapping](../dashboard/web/js/robotarm_3d.js)
- [ROS-2-Mapping](../ros2/src/robotarm_description/robotarm_description/mapping.py)

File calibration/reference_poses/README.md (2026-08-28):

# Referenzpose

Die aktive Wearable-Referenzpose und ihre Messwerte sind in
[`calibration/README.md`](../README.md#wearable-referenzpose) konsolidiert.
Dieser Ordner bleibt als stabiles Ziel fuer den unveraenderten Fotoindex
erhalten.

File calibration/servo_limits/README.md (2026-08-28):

# Servo-Grenzen

Diese Seite bleibt als stabiles Ziel fuer Verweise in den Arduino-Sketches
erhalten. Die vollstaendige aktive Kalibrierung steht in
[`calibration/README.md`](../README.md); Verdrahtung und Sicherheitsgrenzen
stehen in [`docs/HARDWARE.md`](../../docs/HARDWARE.md) und
[`SAFETY.md`](../../SAFETY.md).

| Gelenk | Pin | Min | Max | Start / Timeout / Software-Stop |
| --- | ---: | ---: | ---: | ---: |
| Basis | D9 | 12 Grad | 139 Grad | 75 Grad |
| Schulter | D11 | 35 Grad | 142 Grad | 88 Grad |
| Ellbogen | D3 | 80 Grad | 175 Grad | 127 Grad |
| Handgelenk | D5 | 5 Grad | 177 Grad | 91 Grad |
| Greifer | D6 | 32 Grad | 126 Grad | 79 Grad |

Die Werte wurden am Prototyp empirisch ermittelt. Sie sind keine
zertifizierten Sicherheitsgrenzen. Insbesondere ist `90 Grad` nicht die aktive
Rueckfallpose aller Achsen. Aenderungen erfordern eine erneute mechanische
Pruefung am realen Arm.

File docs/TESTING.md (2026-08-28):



<div align="center">




</div>

---

# Test- und Verifikationsstand

Dieses Dokument unterscheidet bestaetigte `Hardwaretests` von den frischen `Compile- und Statikchecks`. Ein gruener `Build` ersetzt weder einen Flash- noch einen Bewegungstest.

## Bestaetigte Hardwarepfade

Die folgenden Aussagen stammen aus den Projektversuchen bis zum Prototyp-Freeze vom 2026-05-10; sie wurden beim Dokumentationsaudit vom 2026-08-28 nicht erneut auf Hardware ausgefuehrt:

- drei BNO055 am PCA9548A sowie Potentiometer-Greifereingabe am Controller wurden im realen Aufbau betrieben;
- `Controller -> ESP-NOW -> Receiver` ist als lokaler Funkpfad bestaetigt;
- `Receiver -> I2C -> Arduino -> fuenf Servos` wurde zuerst als Sweep und spaeter im Live-I2C-Modus getestet;
- der Live-I2C-Test umfasste Basis, Schulter, Ellbogen, Handgelenk und Greifer und wurde per Compile-Flags aktiviert; der Repo-Default blieb der Sweep;
- `Controller -> Bridge -> WiFi/MQTT -> Pi -> Dashboard/MCP/ROS` wurde als Debug-/Twin-Pfad end-to-end verifiziert.

Diese Nachweise belegen einen funktionierenden Prototyp, aber keine Produktiv-, Safety- oder Security-Freigabe.

## Frischer Softwarecheck vom 2026-08-28

Toolchain und Abhaengigkeiten sind in [`BUILD.md`](BUILD.md#deutsch) festgehalten.

| Check | Ergebnis |
| --- | --- |
| Controller-Compile | erfolgreich, 930311 B Flash / 45544 B RAM |
| Receiver-Compile im Repo-Default | erfolgreich, 902395 B Flash / 45104 B RAM |
| Receiver-Compile Live-I2C mit allen Achsen | erfolgreich, 904751 B Flash / 45136 B RAM |
| Arduino-UNO-Compile | erfolgreich, 4280 B Flash / 282 B RAM |
| Controller-Hotloop-Guard | erfolgreich |
| Receiver-Live-I2C-Guard | erfolgreich |

Die Debug-Bridge wurde in diesem Audit nicht frisch kompiliert. Es wurde nichts geflasht und keine reale Bewegung ausgeloest.

## Guards ausfuehren

Vom Repository-Root:

```powershell
python -B tests/latency/controller_hotloop_guard.py
python -B tests/latency/receiver_live_i2c_guard.py
```

[`controller_hotloop_guard.py`](../tests/latency/controller_hotloop_guard.py) prueft statisch unter anderem:

- langsame BNO055-Status-/Kalibrierabfragen liegen nicht im schnellen Bewegungsloop;
- der Hotpath nutzt gecachten Kalibrierstatus;
- NVS-Offsets werden als effektiver Kalibrierstand behandelt;
- periodischer Serial-Debug und langsame Diagnose sind defaultmaessig aus;
- Einzelkalibrierung verwirft vorhandene Offsets nicht vorzeitig.

[`receiver_live_i2c_guard.py`](../tests/latency/receiver_live_i2c_guard.py) prueft statisch unter anderem:

- Sweep ist Default und Live-I2C ist deaktiviert;
- beide Receiver-Modi koennen nicht gleichzeitig aktiviert werden;
- 50-Hz-, 250-ms-Stale- und Slew-Konstanten sind vorhanden;
- der ESP-NOW-Callback sendet weder I2C noch Serial und puffert nur;
- Notaus und stale Daten werden auf E-Stop beziehungsweise Neutral abgebildet;
- Live-Mapping und achsweise Freigaben bleiben vorhanden.

Die Guards suchen erwartete Quelltextstrukturen. Sie sind Regressionstests, keine Laufzeit-, Funk-, Security- oder Hardwaremessung.

## Vor einer erneuten Hardwarefreigabe offen

- Custom-FQBN aus einem frischen Clone reproduzierbar bereitstellen und den Build damit wiederholen;
- Debug-Bridge frisch kompilieren und ihren Start-/Reconnectpfad pruefen;
- I2C-Idlepegel und 3,3-V-Vertraeglichkeit am konkreten Aufbau messen;
- Notaus, 250-ms-Stale-Reaktion, 1-s-Arduino-Timeout und Neutralziele mit Zeitmessung pruefen;
- Servo-Limits, Stromaufnahme, Blockade, Last, Kabelzug und Dauerlauf testen;
- Funkstoerung, Controller-Neustart, Paketverlust und manipulierte Pakete testen;
- MQTT-ACL, MCP-Publishgrenze, OTA und Credential-Trennung gegen die reale Brokerkonfiguration pruefen;
- Steuerpfad und Debugpfad getrennt auf Ende-zu-Ende-Latenz vermessen.

Die Testuebersicht im Repository liegt in [`tests/README.md`](../tests/README.md). Safety- und Security-Grenzen stehen in [`SAFETY.md`](../SAFETY.md#deutsch) und [`SECURITY.md`](../SECURITY.md#deutsch).

<div align="center">



</div>

---

# Testing and verification status

This document distinguishes confirmed `hardware tests` from the fresh `compile and static checks`. A green `build` replaces neither a flash test nor a motion test.

## Confirmed hardware paths

The following statements originate from project trials up to the prototype freeze on 2026-05-10; they were not rerun on hardware during the documentation audit on 2026-08-28:

- three BNO055 sensors on the PCA9548A and the potentiometer gripper input on the controller were operated in the real setup;
- `Controller -> ESP-NOW -> Receiver` is confirmed as the local radio path;
- `Receiver -> I2C -> Arduino -> five servos` was tested first as a sweep and later in Live-I2C mode;
- the Live-I2C test covered base, shoulder, elbow, wrist, and gripper and was enabled through compile flags; the repository default remained the sweep;
- `Controller -> Bridge -> WiFi/MQTT -> Pi -> Dashboard/MCP/ROS` was verified end to end as the debug/twin path.

This evidence confirms a functional prototype, but it does not grant production, safety, or security approval.

## Fresh software check from 2026-08-28

The toolchain and dependencies are recorded in [`BUILD.md`](BUILD.md#english).

| Check | Result |
| --- | --- |
| Controller compile | successful, 930311 B flash / 45544 B RAM |
| Receiver compile with the repository default | successful, 902395 B flash / 45104 B RAM |
| Receiver compile, Live-I2C with all axes | successful, 904751 B flash / 45136 B RAM |
| Arduino UNO compile | successful, 4280 B flash / 282 B RAM |
| Controller hot-loop guard | successful |
| Receiver Live-I2C guard | successful |

The debug bridge was not freshly compiled in this audit. Nothing was flashed and no real motion was triggered.

## Running the guards

From the repository root:

```powershell
python -B tests/latency/controller_hotloop_guard.py
python -B tests/latency/receiver_live_i2c_guard.py
```

[`controller_hotloop_guard.py`](../tests/latency/controller_hotloop_guard.py) statically checks, among other things, that:

- slow BNO055 status/calibration queries are not located in the fast motion loop;
- the hot path uses cached calibration status;
- NVS offsets are treated as an effective calibration state;
- periodic serial debug output and slow diagnostics are disabled by default;
- individual calibration does not discard existing offsets prematurely.

[`receiver_live_i2c_guard.py`](../tests/latency/receiver_live_i2c_guard.py) statically checks, among other things, that:

- sweep is the default and Live-I2C is disabled;
- both receiver modes cannot be enabled at the same time;
- the 50 Hz, 250 ms stale-data, and slew constants are present;
- the ESP-NOW callback sends neither I2C nor serial data and only buffers;
- emergency-stop and stale data are mapped to E-stop and neutral respectively;
- live mapping and per-axis enables remain present.

The guards look for expected source-code structures. They are regression tests, not runtime, radio, security, or hardware measurements.

## Open before renewed hardware approval

- provide the custom FQBN reproducibly from a fresh clone and repeat the build with it;
- freshly compile the debug bridge and verify its startup/reconnect path;
- measure the I2C idle level and 3.3 V compatibility on the actual setup;
- verify the emergency stop, 250 ms stale-data reaction, 1 s Arduino timeout, and neutral targets with timing measurements;
- test servo limits, current draw, stall, load, cable pull, and endurance operation;
- test radio interference, controller restart, packet loss, and manipulated packets;
- verify the MQTT ACL, MCP publish boundary, OTA, and credential separation against the real broker configuration;
- measure the control path and debug path separately for end-to-end latency.

The repository test overview is located in [`tests/README.md`](../tests/README.md). Safety and security boundaries are documented in [`SAFETY.md`](../SAFETY.md#english) and [`SECURITY.md`](../SECURITY.md#english).

<div align="center">



</div>

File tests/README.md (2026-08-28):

# Tests

Dieser Ordner enthaelt ausfuehrbare Regression-Guards. Der zusammengefuehrte Hardware-, Compile- und Verifikationsstand steht in [`docs/TESTING.md`](../docs/TESTING.md).

## Ausfuehrbare Guards

Vom Repository-Root:

```powershell
python -B tests/latency/controller_hotloop_guard.py
python -B tests/latency/receiver_live_i2c_guard.py
```

- [`controller_hotloop_guard.py`](latency/controller_hotloop_guard.py) schuetzt den Controller-Hotpath vor langsamen Status-/Kalibrierabfragen und prueft die erwarteten Diagnose- und NVS-Regeln.
- [`receiver_live_i2c_guard.py`](latency/receiver_live_i2c_guard.py) schuetzt den deaktivierten Live-I2C-Default, Callback-/Loop-Trennung, Stale-/Notaus-Abbildung und achsweise Freigaben.

Beide Tests analysieren Quelltextstrukturen. Sie simulieren keine Hardware und messen weder Funklatenz noch Servo- oder Security-Verhalten.

## Nachweisarten

| Art | Aussage |
| --- | --- |
| Compile | Quellstand uebersetzt mit dokumentierter Toolchain |
| Guard | erwartete statische Invarianten sind vorhanden |
| Bench | abgegrenzte Hardwarefunktion wurde real beobachtet |
| Integration | kompletter Steuer- oder Debugpfad wurde real verbunden |
| Safety | Fehlerreaktion und physische Grenzen wurden gemessen |
| Security | Angriffs- und Rechteannahmen wurden gegen die reale Konfiguration geprueft |

Compile-Befehle stehen in [`docs/BUILD.md`](../docs/BUILD.md). Safety und Security bleiben getrennt in [`SAFETY.md`](../SAFETY.md) und [`SECURITY.md`](../SECURITY.md). Ein Debug-/Twin-Erfolg ist keine Bewegungs- oder Produktivfreigabe.

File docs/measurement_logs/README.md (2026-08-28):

# Test- und Messnachweise

Der bestaetigte Hardwarepfad, der frische Softwarecheck und alle noch offenen
Nachweise sind in [`docs/TESTING.md`](../TESTING.md) konsolidiert. Die
Git-Historie enthaelt weiterhin die frueheren Einzelprotokolle.

Dieser Ordner bleibt als stabiles Ziel fuer den unveraenderten Fotoindex
erhalten.

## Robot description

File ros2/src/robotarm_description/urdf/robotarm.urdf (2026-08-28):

<?xml version="1.0" ?>
<robot name="adeept_5dof">

  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
  <link name="base_link">
    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
    <inertial><mass value="0.3"/><origin xyz="0 0 0.009"/>
      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</inertial>
  </link>

  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
  <link name="turntable">
    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
    <inertial><mass value="0.05"/><origin xyz="0 0 0.004"/>
      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</inertial>
  </link>

  <joint name="base_joint" type="revolute">
    <parent link="base_link"/><child link="turntable"/>
    <origin xyz="0 0 0.018"/><axis xyz="0 0 1"/>
    <limit lower="-1.5708" upper="1.5708" effort="10" velocity="1.0"/>
  </joint>

  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
  <link name="shoulder_bracket">
    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
    <inertial><mass value="0.12"/><origin xyz="0 0 0.036"/>
      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</inertial>
  </link>

  <joint name="shoulder_bracket_joint" type="fixed">
    <parent link="turntable"/><child link="shoulder_bracket"/>
    <origin xyz="0 0 0.008"/>
  </joint>

  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
  <link name="upper_arm">
    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
    <inertial><mass value="0.12"/><origin xyz="0 0 0.059"/>
      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</inertial>
  </link>

  <joint name="shoulder_joint" type="revolute">
    <parent link="shoulder_bracket"/><child link="upper_arm"/>
    <origin xyz="0 0 0.060"/><axis xyz="1 0 0"/>
    <limit lower="-0.0873" upper="1.3963" effort="10" velocity="1.0"/>
  </joint>

  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
  <link name="forearm">
    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
    <inertial><mass value="0.10"/><origin xyz="0 0 0.054"/>
      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</inertial>
  </link>

  <joint name="elbow_joint" type="revolute">
    <parent link="upper_arm"/><child link="forearm"/>
    <origin xyz="0 0 0.105"/><axis xyz="1 0 0"/>
    <limit lower="-0.0873" upper="1.4835" effort="10" velocity="1.0"/>
  </joint>

  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
  <link name="wrist">
    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
    <inertial><mass value="0.05"/><origin xyz="0 0 0.0225"/>
      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</inertial>
  </link>

  <joint name="wrist_joint" type="revolute">
    <parent link="forearm"/><child link="wrist"/>
    <origin xyz="0 0 0.095"/><axis xyz="0 0 1"/>
    <limit lower="-1.5708" upper="1.5708" effort="5" velocity="1.0"/>
  </joint>

  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
  <link name="gripper_base">
    <inertial><mass value="0.005"/>
      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</inertial>
  </link>

  <joint name="gripper_base_joint" type="fixed">
    <parent link="wrist"/><child link="gripper_base"/>
    <origin xyz="0 0 0.045"/>
  </joint>

  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
  <link name="gripper_left">
    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
    <inertial><mass value="0.01"/><origin xyz="0 0 0.030"/>
      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</inertial>
  </link>

  <joint name="gripper_left_joint" type="revolute">
    <parent link="gripper_base"/><child link="gripper_left"/>
    <origin xyz="-0.008 0 0"/><axis xyz="0 -1 0"/>
    <limit lower="0" upper="0.5" effort="2" velocity="1.0"/>
  </joint>

  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
  <link name="gripper_right">
    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
    <inertial><mass value="0.01"/><origin xyz="0 0 0.030"/>
      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</inertial>
  </link>

  <joint name="gripper_right_joint" type="revolute">
    <parent link="gripper_base"/><child link="gripper_right"/>
    <origin xyz="0.008 0 0"/><axis xyz="0 1 0"/>
    <limit lower="0" upper="0.5" effort="2" velocity="1.0"/>
    <mimic joint="gripper_left_joint" multiplier="1.0" offset="0"/>
  </joint>

</robot>

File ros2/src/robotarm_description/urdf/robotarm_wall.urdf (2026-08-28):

<?xml version="1.0" ?>
<robot name="adeept_5dof_wall">

  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
  <link name="wall">
    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
  </link>

  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

  <link name="base_link_l">
    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
    <inertial><mass value="0.3"/><origin xyz="0 0 0.009"/>
      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</inertial>
  </link>
  <joint name="base_to_wall_l" type="fixed">
    <parent link="wall"/><child link="base_link_l"/>
    <origin xyz="0 0.0025 0.14" rpy="-1.5708 1.5708 0"/>
  </joint>

  <link name="base_link_r">
    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
    <inertial><mass value="0.3"/><origin xyz="0 0 0.009"/>
      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</inertial>
  </link>
  <joint name="base_to_wall_r" type="fixed">
    <parent link="wall"/><child link="base_link_r"/>
    <origin xyz="0 -0.0025 0.14" rpy="1.5708 1.5708 0"/>
  </joint>

  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

  <link name="turntable_l">
    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
    <inertial><mass value="0.05"/><origin xyz="0 0 0.004"/>
      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</inertial>
  </link>
  <joint name="base_joint_l" type="revolute">
    <parent link="base_link_l"/><child link="turntable_l"/>
    <origin xyz="0 0 0.018"/><axis xyz="0 0 1"/>
    <limit lower="-1.5708" upper="1.5708" effort="10" velocity="1.0"/>
  </joint>

  <link name="turntable_r">
    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
    <inertial><mass value="0.05"/><origin xyz="0 0 0.004"/>
      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</inertial>
  </link>
  <joint name="base_joint_r" type="revolute">
    <parent link="base_link_r"/><child link="turntable_r"/>
    <origin xyz="0 0 0.018"/><axis xyz="0 0 -1"/>
    <limit lower="-1.5708" upper="1.5708" effort="10" velocity="1.0"/>
  </joint>

  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

  <link name="shoulder_bracket_l">
    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
    <inertial><mass value="0.12"/><origin xyz="0 0 0.036"/>
      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</inertial>
  </link>
  <joint name="shoulder_bracket_joint_l" type="fixed">
    <parent link="turntable_l"/><child link="shoulder_bracket_l"/>
    <origin xyz="0 0 0.008"/>
  </joint>

  <link name="shoulder_bracket_r">
    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
    <inertial><mass value="0.12"/><origin xyz="0 0 0.036"/>
      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</inertial>
  </link>
  <joint name="shoulder_bracket_joint_r" type="fixed">
    <parent link="turntable_r"/><child link="shoulder_bracket_r"/>
    <origin xyz="0 0 0.008"/>
  </joint>

  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

  <link name="upper_arm_l">
    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
    <inertial><mass value="0.12"/><origin xyz="0 0 0.059"/>
      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</inertial>
  </link>
  <joint name="shoulder_joint_l" type="revolute">
    <parent link="shoulder_bracket_l"/><child link="upper_arm_l"/>
    <origin xyz="0 0 0.060"/><axis xyz="1 0 0"/>
    <limit lower="-0.0873" upper="1.3963" effort="10" velocity="1.0"/>
  </joint>

  <link name="upper_arm_r">
    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
    <inertial><mass value="0.12"/><origin xyz="0 0 0.059"/>
      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</inertial>
  </link>
  <joint name="shoulder_joint_r" type="revolute">
    <parent link="shoulder_bracket_r"/><child link="upper_arm_r"/>
    <origin xyz="0 0 0.060"/><axis xyz="-1 0 0"/>
    <limit lower="-0.0873" upper="1.3963" effort="10" velocity="1.0"/>
  </joint>

  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

  <link name="forearm_l">
    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
    <inertial><mass value="0.10"/><origin xyz="0 0 0.054"/>
      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</inertial>
  </link>
  <joint name="elbow_joint_l" type="revolute">
    <parent link="upper_arm_l"/><child link="forearm_l"/>
    <origin xyz="0 0 0.105"/><axis xyz="1 0 0"/>
    <limit lower="-0.0873" upper="1.4835" effort="10" velocity="1.0"/>
  </joint>

  <link name="forearm_r">
    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
    <inertial><mass value="0.10"/><origin xyz="0 0 0.054"/>
      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</inertial>
  </link>
  <joint name="elbow_joint_r" type="revolute">
    <parent link="upper_arm_r"/><child link="forearm_r"/>
    <origin xyz="0 0 0.105"/><axis xyz="-1 0 0"/>
    <limit lower="-0.0873" upper="1.4835" effort="10" velocity="1.0"/>
  </joint>

  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

  <link name="wrist_l">
    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
    <inertial><mass value="0.05"/><origin xyz="0 0 0.0225"/>
      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</inertial>
  </link>
  <joint name="wrist_joint_l" type="revolute">
    <parent link="forearm_l"/><child link="wrist_l"/>
    <origin xyz="0 0 0.095"/><axis xyz="0 0 1"/>
    <limit lower="-1.5708" upper="1.5708" effort="5" velocity="1.0"/>
  </joint>

  <link name="wrist_r">
    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
    <inertial><mass value="0.05"/><origin xyz="0 0 0.0225"/>
      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</inertial>
  </link>
  <joint name="wrist_joint_r" type="revolute">
    <parent link="forearm_r"/><child link="wrist_r"/>
    <origin xyz="0 0 0.095"/><axis xyz="0 0 -1"/>
    <limit lower="-1.5708" upper="1.5708" effort="5" velocity="1.0"/>
  </joint>

  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

  <link name="gripper_base_l">
    <inertial><mass value="0.005"/>
      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</inertial>
  </link>
  <joint name="gripper_base_joint_l" type="fixed">
    <parent link="wrist_l"/><child link="gripper_base_l"/>
    <origin xyz="0 0 0.045"/>
  </joint>

  <link name="gripper_left_l">
    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
    <inertial><mass value="0.01"/><origin xyz="0 0 0.030"/>
      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</inertial>
  </link>
  <joint name="gripper_joint_l" type="revolute">
    <parent link="gripper_base_l"/><child link="gripper_left_l"/>
    <origin xyz="-0.008 0 0"/><axis xyz="0 -1 0"/>
    <limit lower="0" upper="0.5" effort="2" velocity="1.0"/>
  </joint>

  <link name="gripper_base_r">
    <inertial><mass value="0.005"/>
      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</inertial>
  </link>
  <joint name="gripper_base_joint_r" type="fixed">
    <parent link="wrist_r"/><child link="gripper_base_r"/>
    <origin xyz="0 0 0.045"/>
  </joint>

  <link name="gripper_left_r">
    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
    <inertial><mass value="0.01"/><origin xyz="0 0 0.030"/>
      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</inertial>
  </link>
  <joint name="gripper_joint_r" type="revolute">
    <parent link="gripper_base_r"/><child link="gripper_left_r"/>
    <origin xyz="-0.008 0 0"/><axis xyz="0 -1 0"/>
    <limit lower="0" upper="0.5" effort="2" velocity="1.0"/>
  </joint>

  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

  <link name="gripper_right_l">
    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
    <inertial><mass value="0.01"/><origin xyz="0 0 0.030"/>
      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</inertial>
  </link>
  <joint name="gripper_right_joint_l" type="revolute">
    <parent link="gripper_base_l"/><child link="gripper_right_l"/>
    <origin xyz="0.008 0 0"/><axis xyz="0 1 0"/>
    <limit lower="0" upper="0.5" effort="2" velocity="1.0"/>
    <mimic joint="gripper_joint_l" multiplier="1.0" offset="0"/>
  </joint>

  <link name="gripper_right_r">
    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
    <inertial><mass value="0.01"/><origin xyz="0 0 0.030"/>
      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</inertial>
  </link>
  <joint name="gripper_right_joint_r" type="revolute">
    <parent link="gripper_base_r"/><child link="gripper_right_r"/>
    <origin xyz="0.008 0 0"/><axis xyz="0 1 0"/>
    <limit lower="0" upper="0.5" effort="2" velocity="1.0"/>
    <mimic joint="gripper_joint_r" multiplier="1.0" offset="0"/>
  </joint>

</robot>

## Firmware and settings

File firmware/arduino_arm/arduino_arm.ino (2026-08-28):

// =============================================================================
// Arduino Arm Firmware — I2C Frame V1 Empfang + Servo-Steuerung
// =============================================================================
//
// Empfaengt I2cFrameV1-Frames vom ESP32 Receiver ueber I2C (Wire-Library).
// Arduino ist I2C-Slave (Adresse 0x42), ESP32 ist I2C-Master.
//
// ARCHITEKTUR: Dauerhaft attached (kein Detach-Zyklus!)
//   I2C nutzt die TWI-Hardware-Peripherie des ATmega328P. Der TWI-Interrupt
//   kollidiert NICHT mit Timer1 (Servo-PWM). Deshalb koennen Servos dauerhaft
//   attached bleiben — kein Jitter, kein Detach noetig.
//
//   Vergleich zur alten SoftwareSerial-Loesung:
//     SoftwareSerial: PCINT kollidiert mit Timer1 → Servo-Jitter
//                     → Detach-Zyklus noetig (100ms Listen / 100ms Servo)
//     I2C (Wire):     TWI-Interrupt kollidiert NICHT mit Timer1
//                     → Servos bleiben dauerhaft attached
//                     → Einfacher Code, smoothere Bewegung
//
//   I2C-Verbindung:
//     ESP32 GPIO13 (SDA) → Arduino A4 (SDA) — OLED-Header Pin 3
//     ESP32 GPIO14 (SCL) → Arduino A5 (SCL) — OLED-Header Pin 4
//     ESP32 GND          → Arduino GND       — gemeinsame Masse
//
//   Das OLED-Display muss dafuer ausgesteckt werden (belegt den gleichen Bus).
//
// ISR-DESIGN (KRITISCH!):
//   Der I2C-Empfangs-Callback (bei_i2c_empfang) laeuft im ISR-Kontext.
//   Dort wird NUR Wire.read() in rx_buf[] kopiert — keine Verarbeitung!
//   map()-Berechnungen im ISR verursachten Servo-Zucken (32-Bit Arithmetik
//   auf 8-Bit AVR dauert zu lang und stoert Timer1-PWM).
//   Validierung und map() passieren in loop() via frame_verarbeiten().
//   Siehe: firmware/SERVO_UART_DESIGNENTSCHEIDUNGEN.md Abschnitt 13
//
// NICHT AENDERN ohne das Designdokument zu lesen:
//   - Servo-Limits (firmware/SERVO_UART_DESIGNENTSCHEIDUNGEN.md Abschnitt 4)
//   - Startwerte / Neutralposition (Abschnitt 5)
//   - Slew-Rate-Limiter (Abschnitt 9)
//   - I2C-Migration und ISR-Design (Abschnitt 13)
// =============================================================================

#include <Servo.h>
#include <Wire.h>

// =============================================================================
// I2C-Konfiguration
// =============================================================================
// Slave-Adresse: 0x42 — muss identisch mit I2C_SLAVE_ADDR in i2c_frame.h sein.
// 0x42 wurde gewaehlt weil keine gaengigen I2C-Devices diese Adresse nutzen.
#define I2C_ADDR  0x42

// =============================================================================
// I2C Frame V1 — Protokolldefinition
// =============================================================================
// 11-Byte Binaerprotokoll. Spezifikation: firmware/I2C_FRAME_V1.md
// MUSS identisch sein mit firmware/esp32_receiver/i2c_frame.h

#define FRAME_START_A    0xA5   // Magic Byte 1 — Frame-Identifikation
#define FRAME_START_B    0x5A   // Magic Byte 2
#define FRAME_VERSION    1      // Protokollversion — Frames anderer Version werden ignoriert
#define FRAME_SIZE       11     // Gesamtgroesse in Bytes inkl. CRC

#define FLAG_VALID       (1 << 0)  // Bit 0: Daten sind gueltig und sollen angewandt werden
#define FLAG_NEUTRAL     (1 << 1)  // Bit 1: Alle Achsen auf Neutralposition fahren
#define FLAG_ESTOP       (1 << 3)  // Bit 3: Notaus — sofort auf Neutral

typedef struct __attribute__((packed)) {
    uint8_t start_a;            // 0xA5
    uint8_t start_b;            // 0x5A
    uint8_t protokoll_version;  // Muss FRAME_VERSION entsprechen
    uint8_t sequenz;            // Auto-Inkrement, fuer Debugging/Paketverlust-Erkennung
    uint8_t flags;              // FLAG_VALID, FLAG_NEUTRAL, FLAG_ESTOP
    uint8_t basis_soll;         // 0-255, wird auf BASE_MIN..BASE_MAX gemappt
    uint8_t schulter_soll;      // 0-255, wird auf SHOULDER_MIN..SHOULDER_MAX gemappt
    uint8_t ellbogen_soll;      // 0-255, wird auf ELBOW_MIN..ELBOW_MAX gemappt
    uint8_t handgelenk_soll;    // 0-255, wird auf WRIST_MIN..WRIST_MAX gemappt
    uint8_t greifer_soll;       // 0-255, wird auf GRIPPER_MIN..GRIPPER_MAX gemappt
    uint8_t crc8;               // XOR ueber Bytes 0-9
} FrameV1;

// =============================================================================
// Servo-Konfiguration — reale Verkabelung + gemessene Limits
// =============================================================================
// Pin-Zuordnung weicht vom Adeept-Standard ab! Empirisch ermittelt.
// Quelle: memory/project_servo_pin_mapping.md
// Limits: Mit Potentiometer-Sketch an physischen Endanschlaegen gemessen.
// Quelle: calibration/servo_limits/README.md
// Details: firmware/SERVO_UART_DESIGNENTSCHEIDUNGEN.md Abschnitt 4
//
// NICHT AENDERN ohne physische Nachmessung am Arm!

#define SERVO_BASE_PIN      9    // Base/Drehung — Poti A0
#define SERVO_GRIPPER_PIN   6    // Greifer — Poti A1
#define SERVO_WRIST_PIN     5    // Handgelenk — Poti A2
#define SERVO_ELBOW_PIN     3    // Ellbogen — Poti A3
#define SERVO_SHOULDER_PIN  11   // Schulter — Poti A6

#define BASE_MIN       12   // Vollstaendig rechts gedreht
#define BASE_MAX      139   // Vollstaendig links (mathematisch positiv)
#define GRIPPER_MIN    32   // Komplett geoeffnet
#define GRIPPER_MAX   126   // Komplett geschlossen
#define WRIST_MIN       5   // Im Uhrzeigersinn (mathematisch negativ)
#define WRIST_MAX     177   // Gegen Uhrzeigersinn (mathematisch positiv)
#define ELBOW_MIN      80   // Komplett gerade (Arm gestreckt)
#define ELBOW_MAX     175   // Komplett eingeklappt
#define SHOULDER_MIN   35   // Komplett eingeklappt
#define SHOULDER_MAX  142   // BEWUSST LIMITIERT — physisch gaenge mehr, aber
                            // mechanische Belastung und Kollisionsgefahr!

// =============================================================================
// Timing
// =============================================================================
#define TIMEOUT_MS   1000   // Wenn 1s kein Frame: Neutral setzen
#define LOOP_MS      20     // 50 Hz Servo-Update-Rate (20ms = 1 PWM-Zyklus)

Servo servoBase, servoGripper, servoWrist, servoElbow, servoShoulder;

unsigned long letzter_frame_ms = 0;  // Zeitstempel des letzten gueltigen Frames

// =============================================================================
// Servo-Zielwinkel — Startwerte = Mittelposition jedes Gelenks
// =============================================================================
// WICHTIG: NICHT pauschal 90 Grad verwenden!
// Die Mittelwerte (MIN+MAX)/2 entsprechen dem, was der ESP32-Sweep bei
// SWEEP_NEUTRAL=128 sendet: map(128, 0, 255, MIN, MAX) ≈ (MIN+MAX)/2.
// Bei pauschal 90 Grad springt z.B. der Ellbogen um 37 Grad beim ersten Frame.
// Siehe: firmware/SERVO_UART_DESIGNENTSCHEIDUNGEN.md Abschnitt 5

// Maximale Grad-Aenderung pro Loop-Durchlauf (Slew-Rate-Limiter).
// Bei 50 Hz Loop und MAX_SCHRITT=3: max 150 Grad/Sekunde.
// Glaettet Bewegung, bleibt fuer den ersten echten Greifer-Test aber reaktionsfreudig.
#define MAX_SCHRITT  3

// ziel[] = Sollwert vom letzten empfangenen Frame (gesetzt im I2C-Interrupt)
// aktuell[] = tatsaechliche Servo-Position (interpoliert in loop())
// ziel[] wird NUR in loop() geschrieben (frame_verarbeiten()) und gelesen.
// Kein volatile noetig — ISR schreibt nur in rx_buf/rx_bereit.
int ziel[5] = {
    (BASE_MIN + BASE_MAX) / 2,         // 75 — Base Mitte
    (SHOULDER_MIN + SHOULDER_MAX) / 2,  // 88 — Shoulder Mitte
    (ELBOW_MIN + ELBOW_MAX) / 2,       // 127 — Elbow Mitte
    (WRIST_MIN + WRIST_MAX) / 2,       // 91 — Wrist Mitte
    (GRIPPER_MIN + GRIPPER_MAX) / 2    // 79 — Gripper Mitte
};
int aktuell[5] = {
    (BASE_MIN + BASE_MAX) / 2,
    (SHOULDER_MIN + SHOULDER_MAX) / 2,
    (ELBOW_MIN + ELBOW_MAX) / 2,
    (WRIST_MIN + WRIST_MAX) / 2,
    (GRIPPER_MIN + GRIPPER_MAX) / 2
};

// I2C-Empfangspuffer — ISR schreibt nur Rohbytes, loop() verarbeitet.
// GRUND: map() im ISR dauert zu lang auf 8-Bit AVR (32-Bit Multiplikation/Division)
// und stoert Timer1-Servo-PWM → sichtbares Zucken aller Servos.
volatile uint8_t rx_buf[FRAME_SIZE];
volatile bool rx_bereit = false;

// CRC8 — XOR ueber alle Bytes. Muss identisch mit i2c_frame.h sein.
uint8_t crc_berechnen(const uint8_t* daten, uint8_t laenge) {
    uint8_t summe = 0;
    for (uint8_t i = 0; i < laenge; i++) summe ^= daten[i];
    return summe;
}

// =============================================================================
// I2C Empfangs-Callback (ISR-Kontext!)
// =============================================================================
// NUR Bytes lesen und in rx_buf kopieren. Keinerlei Verarbeitung!
// Alles andere (Validierung, map(), ziel[]-Update) passiert in loop().
void bei_i2c_empfang(int anzahl_bytes) {
    if (anzahl_bytes != FRAME_SIZE) {
        while (Wire.available()) Wire.read();
        return;
    }
    for (uint8_t i = 0; i < FRAME_SIZE; i++) {
        rx_buf[i] = Wire.read();
    }
    rx_bereit = true;
}

// Frame aus rx_buf validieren und ziel[] aktualisieren.
// Wird in loop() aufgerufen — NICHT im ISR!
void frame_verarbeiten() {
    uint8_t buf[FRAME_SIZE];
    // Lokale Kopie erstellen (rx_buf ist volatile)
    noInterrupts();
    for (uint8_t i = 0; i < FRAME_SIZE; i++) buf[i] = rx_buf[i];
    rx_bereit = false;
    interrupts();

    // Magic Bytes pruefen
    if (buf[0] != FRAME_START_A || buf[1] != FRAME_START_B) return;

    FrameV1* frame = (FrameV1*)buf;

    if (frame->protokoll_version != FRAME_VERSION) return;
    if (frame->crc8 != crc_berechnen(buf, FRAME_SIZE - 1)) return;

    // Frame ist gueltig
    letzter_frame_ms = millis();

    if (frame->flags & FLAG_ESTOP || frame->flags & FLAG_NEUTRAL) {
        neutral_setzen();
        return;
    }
    if (!(frame->flags & FLAG_VALID)) return;

    ziel[0] = map(frame->basis_soll, 0, 255, BASE_MIN, BASE_MAX);
    ziel[1] = map(frame->schulter_soll, 0, 255, SHOULDER_MIN, SHOULDER_MAX);
    ziel[2] = map(frame->ellbogen_soll, 0, 255, ELBOW_MIN, ELBOW_MAX);
    ziel[3] = map(frame->handgelenk_soll, 0, 255, WRIST_MIN, WRIST_MAX);
    ziel[4] = map(frame->greifer_soll, 0, 255, GRIPPER_MIN, GRIPPER_MAX);
}

// =============================================================================
// Servo-Steuerung
// =============================================================================

// Slew-Rate-Limiter: aktuell[] bewegt sich pro Durchlauf max MAX_SCHRITT Grad
// Richtung ziel[]. Glaettet Bewegung und verhindert harte Spruenge.
void slew_update() {
    for (int i = 0; i < 5; i++) {
        if (aktuell[i] < ziel[i]) {
            aktuell[i] = min(aktuell[i] + MAX_SCHRITT, ziel[i]);
        } else if (aktuell[i] > ziel[i]) {
            aktuell[i] = max(aktuell[i] - MAX_SCHRITT, ziel[i]);
        }
    }
}

// Alle Achsen auf Mittelposition setzen (bei Timeout).
// Verwendet (MIN+MAX)/2 statt pauschal 90 — siehe Abschnitt 5 im Designdokument.
void neutral_setzen() {
    ziel[0] = (BASE_MIN + BASE_MAX) / 2;
    ziel[1] = (SHOULDER_MIN + SHOULDER_MAX) / 2;
    ziel[2] = (ELBOW_MIN + ELBOW_MAX) / 2;
    ziel[3] = (WRIST_MIN + WRIST_MAX) / 2;
    ziel[4] = (GRIPPER_MIN + GRIPPER_MAX) / 2;
}

// =============================================================================
// Setup
// =============================================================================
void setup() {
    // Servos einmalig attachen und auf Startposition fahren.
    // REIHENFOLGE KRITISCH: attach() sendet kurz 90-Grad-Puls (Servo-Library Default).
    // Durch sofortiges write() nach jedem attach() wird der Glitch minimiert.
    // Siehe: firmware/SERVO_UART_DESIGNENTSCHEIDUNGEN.md Abschnitt 3
    servoBase.attach(SERVO_BASE_PIN);
    servoBase.write(aktuell[0]);
    servoShoulder.attach(SERVO_SHOULDER_PIN);
    servoShoulder.write(aktuell[1]);
    servoElbow.attach(SERVO_ELBOW_PIN);
    servoElbow.write(aktuell[2]);
    servoWrist.attach(SERVO_WRIST_PIN);
    servoWrist.write(aktuell[3]);
    servoGripper.attach(SERVO_GRIPPER_PIN);
    servoGripper.write(aktuell[4]);

    // I2C-Slave initialisieren
    Wire.begin(I2C_ADDR);
    Wire.onReceive(bei_i2c_empfang);

    letzter_frame_ms = millis();
}

// =============================================================================
// Hauptschleife — einfacher 50 Hz Servo-Update
// =============================================================================
// Kein Detach-Zyklus mehr! I2C-Empfang laeuft im Hintergrund per TWI-Interrupt.
// loop() macht nur noch:
//   1. Slew-Update (aktuell[] Richtung ziel[] bewegen)
//   2. Servo-Positionen schreiben
//   3. Timeout pruefen
//   4. 20ms warten (= 50 Hz, passt zu Servo-PWM-Frequenz)
void loop() {
    // Neuen Frame verarbeiten (Validierung + map() hier statt im ISR)
    if (rx_bereit) {
        frame_verarbeiten();
    }

    // Slew-Update und Servo-Positionen schreiben
    slew_update();
    servoBase.write(aktuell[0]);
    servoShoulder.write(aktuell[1]);
    servoElbow.write(aktuell[2]);
    servoWrist.write(aktuell[3]);
    servoGripper.write(aktuell[4]);

    // Timeout: Keine Frames seit 1 Sekunde → Sicherheits-Neutral
    if (millis() - letzter_frame_ms > TIMEOUT_MS) {
        neutral_setzen();
        letzter_frame_ms = millis();
    }

    delay(LOOP_MS);
}

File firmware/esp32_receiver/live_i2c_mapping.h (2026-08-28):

#ifndef LIVE_I2C_MAPPING_H
#define LIVE_I2C_MAPPING_H

#include <Arduino.h>
#include <math.h>

// Fachliches Mapping fuer den spaeteren Live-I2C-Pfad.
// Die Konstanten spiegeln den aktuell verifizierten Dashboard-/ROS-Twin-Stand.

typedef struct {
    uint8_t basis;
    uint8_t schulter;
    uint8_t ellbogen;
    uint8_t handgelenk;
    uint8_t greifer;
    float handgelenk_raw_deg;
    float handgelenk_deg;
} LiveI2cZiele;

typedef struct {
    float x;
    float y;
    float z;
    float w;
} LiveQuaternion;

static const SensorDaten REFERENCE_POSE[ANZAHL_SENSOREN] = {
    {255.0f, -5.5f, 65.8f},   // S0 = Hand/Wrist
    {260.3f, -10.7f, 86.0f},  // S1 = Unterarm
    {280.8f, 13.2f, 88.9f},   // S2 = Oberarm
};

#define LIVE_BASE_LIFT_MIN       0.0f
#define LIVE_BASE_LIFT_MAX     100.0f
#define LIVE_SHOULDER_INPUT_MIN -60.0f
#define LIVE_SHOULDER_INPUT_MAX 60.0f
#define LIVE_SHOULDER_REFERENCE_HEADING 240.0f
#define LIVE_ELBOW_INPUT_MIN     0.0f
#define LIVE_ELBOW_INPUT_MAX    45.0f
#define LIVE_WRIST_MIN_DEG     -90.0f
#define LIVE_WRIST_MAX_DEG      90.0f
#define LIVE_WRIST_CENTER_OFFSET_DEG 10.2f
#define LIVE_WRIST_POSITIVE_GAIN      1.0f
#define LIVE_WRIST_NEGATIVE_GAIN      1.0f
#define LIVE_WRIST_ABS_FALLBACK_MIN_DEG 35.0f
#define LIVE_WRIST_ABS_FALLBACK_REL_MAX_DEG 25.0f
#define LIVE_WRIST_WRAP_REJECT_DEG   90.0f
#define LIVE_WRIST_SAFE_MIN_DEG     -75.0f
#define LIVE_WRIST_SAFE_MAX_DEG      75.0f
#define LIVE_WRIST_FOLD_PITCH_ABS_DEG 145.0f
#define LIVE_WRIST_FOLD_LATCH_MIN_DEG 30.0f
#define LIVE_WRIST_FOLD_MARGIN_DEG     3.0f
#define LIVE_WRIST_FOLD_RELEASE_MARGIN_DEG 1.0f

static bool live_wrist_initialized = false;
static bool live_wrist_zero_pending = false;
static bool live_wrist_zero_done = false;
static bool live_wrist_fold_latched = false;
static float live_wrist_fold_sign = 0.0f;
static float live_wrist_fold_hold_deg = 0.0f;
static float live_wrist_center_offset_deg = LIVE_WRIST_CENTER_OFFSET_DEG;
static float live_wrist_last_deg = 0.0f;
static uint8_t live_shoulder_last_byte = 128;
static bool live_elbow_initialized = false;
static uint8_t live_elbow_last_byte = 128;

static float clamp_float(float wert, float min_wert, float max_wert) {
    if (wert < min_wert) return min_wert;
    if (wert > max_wert) return max_wert;
    return wert;
}

static float normalize_heading_delta(float current_deg, float reference_deg) {
    float delta = current_deg - reference_deg;
    while (delta > 180.0f) delta -= 360.0f;
    while (delta < -180.0f) delta += 360.0f;
    return delta;
}

static float map_linear(float wert, float in_min, float in_max, float out_min, float out_max) {
    if (in_max == in_min) return out_min;
    return out_min + ((wert - in_min) / (in_max - in_min)) * (out_max - out_min);
}

static uint8_t byte_aus_float(float wert, float in_min, float in_max) {
    float byte_wert = map_linear(clamp_float(wert, in_min, in_max), in_min, in_max, 0.0f, 255.0f);
    if (byte_wert < 0.0f) return 0;
    if (byte_wert > 255.0f) return 255;
    return (uint8_t)(byte_wert + 0.5f);
}

static LiveQuaternion quaternion_multiply(LiveQuaternion a, LiveQuaternion b) {
    LiveQuaternion q;
    q.x = a.w * b.x + a.x * b.w + a.y * b.z - a.z * b.y;
    q.y = a.w * b.y - a.x * b.z + a.y * b.w + a.z * b.x;
    q.z = a.w * b.z + a.x * b.y - a.y * b.x + a.z * b.w;
    q.w = a.w * b.w - a.x * b.x - a.y * b.y - a.z * b.z;
    return q;
}

static LiveQuaternion quaternion_normalize(LiveQuaternion q) {
    float norm = sqrtf(q.x * q.x + q.y * q.y + q.z * q.z + q.w * q.w);
    if (norm == 0.0f) return {0.0f, 0.0f, 0.0f, 1.0f};
    return {q.x / norm, q.y / norm, q.z / norm, q.w / norm};
}

static LiveQuaternion quaternion_inverse(LiveQuaternion q) {
    LiveQuaternion n = quaternion_normalize(q);
    return {-n.x, -n.y, -n.z, n.w};
}

static LiveQuaternion axis_angle_quaternion(float x, float y, float z, float angle_rad) {
    float half = angle_rad / 2.0f;
    float s = sinf(half);
    return {x * s, y * s, z * s, cosf(half)};
}

static LiveQuaternion sensor_quaternion(const SensorDaten* sensor) {
    LiveQuaternion qx = axis_angle_quaternion(1.0f, 0.0f, 0.0f, radians(sensor->roll));
    LiveQuaternion qy = axis_angle_quaternion(0.0f, 1.0f, 0.0f, radians(sensor->pitch));
    LiveQuaternion qz = axis_angle_quaternion(0.0f, 0.0f, 1.0f, radians(sensor->heading));
    return quaternion_normalize(quaternion_multiply(quaternion_multiply(qx, qy), qz));
}

static float relative_wrist_twist_deg(const SensorDaten* hand_sensor, const SensorDaten* forearm_sensor) {
    LiveQuaternion q_hand = sensor_quaternion(hand_sensor);
    LiveQuaternion q_forearm = sensor_quaternion(forearm_sensor);
    LiveQuaternion q_rel = quaternion_multiply(quaternion_inverse(q_forearm), q_hand);
    LiveQuaternion twist = quaternion_normalize({q_rel.x, 0.0f, 0.0f, q_rel.w});
    float twist_deg = degrees(2.0f * atan2f(twist.x, twist.w));
    return normalize_heading_delta(twist_deg, 0.0f);
}
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

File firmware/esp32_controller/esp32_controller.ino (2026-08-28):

#include <WiFi.h>
#include <esp_now.h>
#include <esp_wifi.h>
#include <esp_mac.h>
#include <Wire.h>
#include <Adafruit_Sensor.h>
#include <Adafruit_BNO055.h>
#include <Preferences.h>
#include <Adafruit_NeoPixel.h>

// Controller: IMU-Daten lesen und per ESP-NOW senden
// I2C: SDA GPIO8 / SCL GPIO9 | Mux: 0x70 | Sensoren: 0x29
// Peer-Adresse kommt aus peer_config.local.h (gitignored)
// Vorlage: peer_config.template.h
//
// Kalibrierung: Offsets werden im NVS gespeichert und beim Boot geladen.
// Befehle ueber Serial:
//   RECAL    — alle Offsets loeschen, Neukalibrierung
//   CAL0     — Einzelkalibrierung Sensor 0 (Mux bleibt offen)
//   CAL1     — Einzelkalibrierung Sensor 1
//   CAL2     — Einzelkalibrierung Sensor 2
//   STOP     — Einzelkalibrierung abbrechen, Normalbetrieb
//
// Aktuelle Segmentzuordnung (Stand 2026-04-22):
//   S0 = Hand/Wrist (Mux-Kanal 0)
//   S1 = Unterarm   (Mux-Kanal 1)
//   S2 = Oberarm    (Mux-Kanal 2)
//
// LED-Debugging (alle mit 100 Ohm Vorwiderstand):
//   GPIO4  Blau   — Oberarm-IMU (S2)
//   GPIO5  Rot    — Unterarm-IMU (S1)
//   GPIO6  Weiss  — Hand/Wrist-IMU (S0)
//   GPIO7  Gruen  — COMMS
//   GPIO10 ?      — FAULT (externe Farbe separat pruefen)
//
// Notaus-Schalter (GPIO21):
//   Toggle-Button nach GND mit internem Pull-Up.
//   Jeder Tastendruck toggelt den Notaus-Zustand.
//   Entprellung: 50ms, Zustandswechsel wird geloggt und per FAULT-LED angezeigt.
//   LED-Schema: AUS = OK, AN = Problem/Notaus.

#include "peer_config.local.h"

#define I2C_SDA           8
#define I2C_SCL           9
#define MUX_ADRESSE       0x70
#define BNO_ADRESSE       0x29
#define ANZAHL_SENSOREN   3
#define SENDE_INTERVALL   5     // ms
#define PROTOKOLL_VERSION 4

#define NOTAUS_PIN       21     // Toggle-Button nach GND, interner Pull-Up
#define NOTAUS_ENTPRELL   50    // ms Entprellzeit

#define FLEX_PIN          1
// Poti-Arbeitsstand 2026-04-23:
// Der defekte Flex-Sensor wird temporaer durch einen 10k-Poti ersetzt.
// Verdrahtung im aktuellen 2-Draht-Aufbau:
//   bestehende 3.3V-Leitung          -> aeusserer Poti-Pin
//   bestehende ADC-/Teiler-Leitung   -> mittlerer Poti-Pin (Wischer)
//   10k Pull-Down gegen GND bleibt auf dem Controller bestehen
//
// Im aktuellen Live-Aufbau wurde gemessen:
//   offen / Ruhelage  ~= 1935 ADC
//   geschlossen / zu  ~= 3020 ADC
// OFFEN/Ruhelage soll 0% liefern, ZU soll Richtung 100% gehen.
#define FLEX_GERADE       1935
#define FLEX_GEBOGEN      3020
#define FLEX_FILTER_ALPHA  0.18f
#define FLEX_RAW_DEADBAND   2.0f

#define KALIB_SCHWELLE_GYRO  3
#define KALIB_SCHWELLE_ACCEL 3
#define KALIB_SCHWELLE_MAG   3
#define KALIB_SAVE_STABLE_COUNT 3

// LED-Pins: historische Namen beibehalten, reale Farben/Zuordnung siehe Header oben
#define LED_HAND          4   // GPIO4  — reale externe LED: Blau   — S2 Oberarm
#define LED_UNTERARM      5   // GPIO5  — reale externe LED: Rot    — S1 Unterarm
#define LED_OBERARM       6   // GPIO6  — reale externe LED: Weiss  — S0 Hand/Wrist
#define LED_COMMS         7   // GPIO7  — reale externe LED: Gruen  — Kommunikation
#define LED_FAULT        10   // GPIO10 — externe FAULT-LED, Farbe separat pruefen
#define RGB_PIN          48   // Interne RGB-LED
#define RGB_ANZAHL        1

// Flags-Bitfeld (ImuPaket v4)
#define FLAG_NOTAUS       (1 << 0)   // Bit 0: Notaus aktiv
// Bits 1-7: reserviert fuer spaetere Erweiterung (Sensor-Gueltigkeit, Auth, etc.)

// Zuordnung: LED-Pin pro Sensor-Index (S0=Hand/Wrist, S1=Unterarm, S2=Oberarm)
Adafruit_NeoPixel rgb(RGB_ANZAHL, RGB_PIN, NEO_GRB + NEO_KHZ800);

static const uint8_t led_sensor_pin[ANZAHL_SENSOREN] = {
    LED_OBERARM,    // S0
    LED_UNTERARM,   // S1
    LED_HAND        // S2
};

static const char* sensor_segment_name[ANZAHL_SENSOREN] = {
    "Hand/Wrist",
    "Unterarm",
    "Oberarm"
};

static const char* sensor_led_name[ANZAHL_SENSOREN] = {
    "Weiss/GPIO6",
    "Rot/GPIO5",
    "Blau/GPIO4"
};

typedef struct {
    float heading;
    float roll;
    float pitch;
} SensorDaten;

typedef struct {
    uint8_t sys;
    uint8_t gyro;
    uint8_t accel;
    uint8_t mag;
} KalibStatus;

typedef struct __attribute__((packed)) {
    uint32_t    zaehler;
    SensorDaten sensoren[ANZAHL_SENSOREN];
    KalibStatus kalib[ANZAHL_SENSOREN];
    float       flex_prozent;
    uint8_t     flags;               // Bitfeld: Bit 0 = Notaus, Bits 1-7 reserviert
    uint8_t     protokoll_version;   // 4
    uint8_t     pruefsumme;
} ImuPaket;

Adafruit_BNO055 sensoren[ANZAHL_SENSOREN] = {
    Adafruit_BNO055(55, BNO_ADRESSE, &Wire),
    Adafruit_BNO055(56, BNO_ADRESSE, &Wire),
    Adafruit_BNO055(57, BNO_ADRESSE, &Wire),
};

Preferences prefs;
static uint32_t sende_zaehler = 0;
static bool kalib_gespeichert[ANZAHL_SENSOREN] = {false, false, false};
static uint8_t kalib_stabil_zaehler[ANZAHL_SENSOREN] = {0, 0, 0};
static bool sensor_bereit[ANZAHL_SENSOREN] = {false, false, false};
static KalibStatus letzter_kalib_status[ANZAHL_SENSOREN] = {
    {0, 0, 0, 0},
    {0, 0, 0, 0},
    {0, 0, 0, 0}
};
static SensorDaten letzter_gueltiger_sensor[ANZAHL_SENSOREN] = {
    {0.0f, 0.0f, 0.0f},
    {0.0f, 0.0f, 0.0f},
    {0.0f, 0.0f, 0.0f}
};
static bool letzter_gueltiger_sensor_vorhanden[ANZAHL_SENSOREN] = {false, false, false};
static uint32_t sensor_nullframe_hold_zaehler[ANZAHL_SENSOREN] = {0, 0, 0};
static bool letzter_tx_ok = false;
static bool fehler_aktiv = false;
static bool flex_bereit = true;
static bool flex_filter_initialisiert = false;
static float flex_roh_gefiltert = 0.0f;
#if BRIDGE_AKTIV
static bool bridge_registriert = false;
#endif

// Notaus-Zustand (Toggle-Button, entprellt)
static bool notaus_aktiv = false;
static bool notaus_letzter_pegel = HIGH;       // Pull-Up: Ruhezustand = HIGH
static bool notaus_pegel_stabil = HIGH;        // letzter stabiler Pegel
static unsigned long notaus_letzte_aenderung_ms = 0;

// Status-Debug ist im Livebetrieb standardmaessig aus, weil grosse
// Serial-Bloecke messbare Paketpausen verursachen koennen.
#define DEBUG_INTERVALL 2000  // ms
static bool debug_status_aktiv = false;
static unsigned long letzter_debug_ms = 0;
static unsigned long letzter_loop_start_us = 0;
static uint32_t timing_samples = 0;
static uint64_t timing_interval_sum_us = 0;
static uint32_t timing_interval_max_us = 0;
static uint64_t timing_hotpath_sum_us = 0;
static uint32_t timing_hotpath_max_us = 0;

// Langsame Diagnose getrennt vom Bewegungs-Hotpath:
// Pro Intervall wird nur ein Sensor geprueft. Bei drei Sensoren bekommt jeder
// Sensor etwa alle 6s einen frischen Status. Im Livebetrieb ist das aus,
// weil BNO055-Statusabfragen die naechste Paket-Runde sichtbar blockieren.
#define STATUS_CHECK_INTERVALL 2000  // ms
#define MUX_SETTLE_DELAY         5   // ms nach Kanalwechsel
static bool status_diag_aktiv = false;
static unsigned long letzter_status_check_ms = 0;
static uint8_t status_check_sensor = 0;

// Einzelkalibrierungsmodus: -1 = aus, 0/1/2 = aktiver Sensor
static int8_t kalib_einzeln = -1;
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
